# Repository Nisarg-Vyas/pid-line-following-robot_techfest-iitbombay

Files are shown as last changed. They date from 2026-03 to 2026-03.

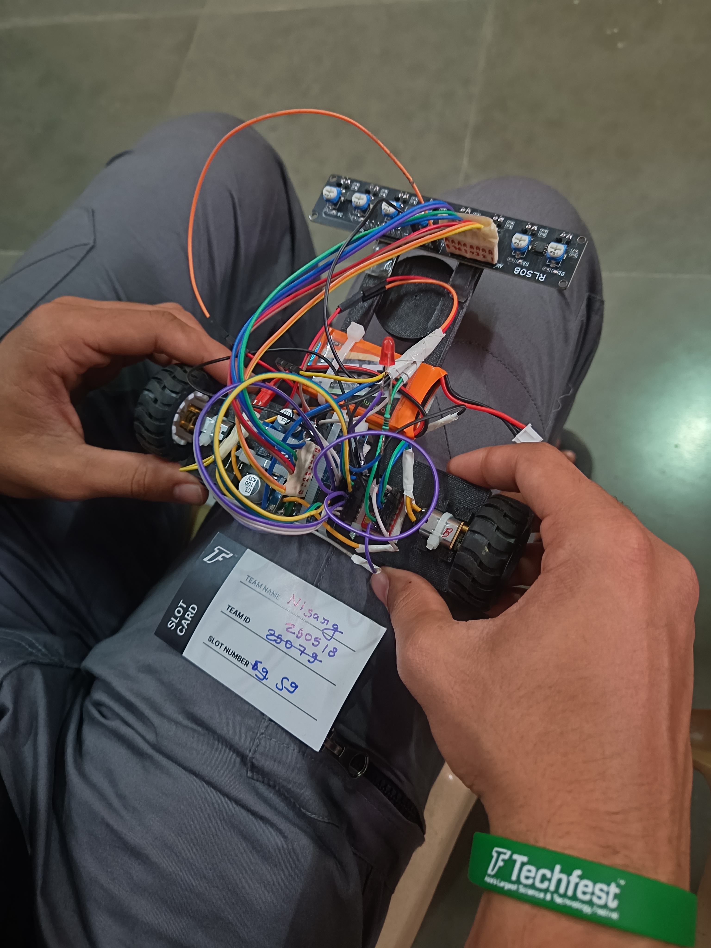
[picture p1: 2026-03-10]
images/lfr_1.jpg

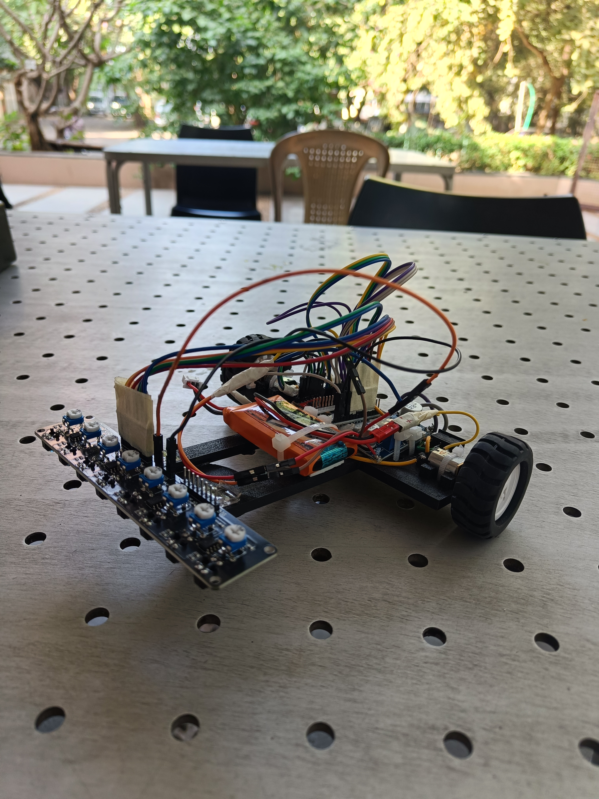
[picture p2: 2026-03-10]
images/lfr_2.jpg

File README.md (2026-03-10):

# PID Line Following Robot (Techfest IIT Bombay – Meshmerize)

A high-speed PID-based Line Following Robot designed for the **Meshmerize competition organised by Techfest IIT Bombay**.

The robot secured **3rd place in the Zonal round at IIT Gandhinagar** and directly qualified for the **final round**.

The robot uses an **8-channel reflectance sensor array**, a **PID control algorithm**, and a **dual H-bridge motor driver** to achieve stable and fast line tracking. (check [lfr_demo](videos/lfr_demo.mp4))

---

# Competition Performance

The robot performed very well in the zonal round and achieved **3rd position**, qualifying directly for the finals.

During the final round, the robot was tuned for **higher speed**, which caused the sensors to miss the line on sharp turns. However, at moderate speeds the robot was able to follow the track very accurately.

---

# Features

* PID based line following
* 8-channel reflectance sensor array
* Junction detection
* U-turn detection
* Dead-end detection
* Finish box detection
* Adjustable motor speed
* High-speed optimized control

---

# Hardware Components

Main components used:

* Arduino Nano
* QTR-8RC reflectance sensor array
* TB6612FNG motor driver
* N20 DC gear motors
* LiPo battery (7.4V)
* Buck converter for regulated voltage
* LEDs for status indication

The complete component list is available in:

[View COMPONENTS](docs/components.txt)

---

# System Architecture

The robot consists of three main subsystems:

### Sensor System

An **8-channel reflectance sensor array** reads the track.

Each sensor returns a value representing how much light is reflected from the surface.

* Dark line → low reflectance
* White surface → high reflectance

The sensors are read through the Arduino analog pins.

---

### Control System

The robot uses a **PID controller** to adjust motor speeds based on the line position.

The PID algorithm calculates the error between the detected line position and the center of the robot.

Correction formula:

```
correction = Kp * error + Kd * (error - lastError)
```

Motor speeds are adjusted accordingly to steer the robot back onto the line.

---

### Drive System

Two **N20 DC gear motors** drive the robot using a differential drive configuration.

The **TB6612FNG motor driver** controls direction and speed using PWM signals from the Arduino.

---

# Code Explanation

The control logic is implemented using a **state machine**.

States include:

* FOLLOW_LINE
* TURN_LEFT_STATE
* TURN_RIGHT_STATE
* UTURN_STATE
* FINISH_STATE

The robot continuously reads sensor values and determines which state to enter.

---

# Line Following Algorithm

The robot reads all 8 sensors and calculates a weighted average of their readings.

Example sensor weights:

```
{-3, -2, -1, -0.5, 0.5, 1, 2, 3}
```

These weights estimate the line position relative to the robot center.

The error is then fed into the PID controller to compute steering correction.

---

# Junction Detection

The robot checks specific sensors to determine junctions.

Left junction:

```
sensor[6] or sensor[7]
```

Right junction:

```
sensor[0] or sensor[1]
```

Straight path detection is based on center sensors.

---

# Dead-End Detection

If no valid path is detected, the robot identifies a **dead end** and performs a **U-turn**.

---

# Finish Detection

A white finish box is detected when all sensors detect a white surface for a sustained period.

Once detected:

* motors stop
* finish LED turns ON

---

# Pin Configuration

Motor Driver:

| Arduino Pin | Function |
| --- | --- |
| 7 | AIN1 |
| 6 | AIN2 |
| 5 | PWMA |
| 9 | BIN1 |
| 10 | BIN2 |
| 11 | PWMB |
| 8 | STBY |

Sensor Enable:

| Arduino Pin | Function |
| --- | --- |
| 4 | IR Sensor Enable |

Finish LED:

| Arduino Pin | Function |
| --- | --- |
| 13 | Finish Indicator |

Complete wiring details are available in:

docs/pinout_wiring.txt

---

# Future Improvements

* adaptive PID tuning
* higher sensor sampling rate
* dynamic speed control
* improved corner detection
* hardware encoder feedback

---

# Author
Nisarg Vyas  
B.Tech Computer Science and Engineering  
IIIT Vadodara (IIITV-ICD)

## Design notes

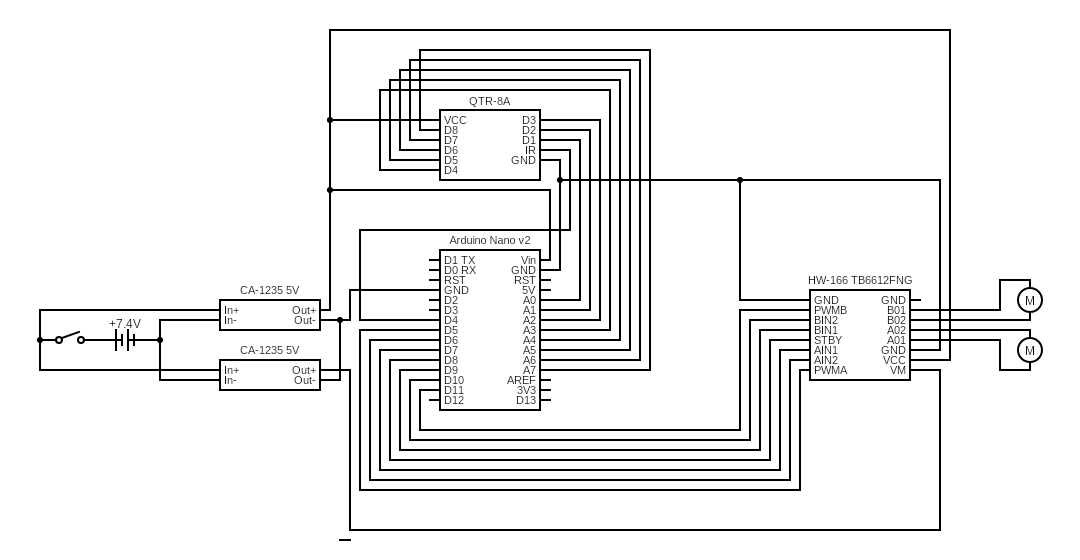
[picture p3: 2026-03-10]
docs/circuit.png

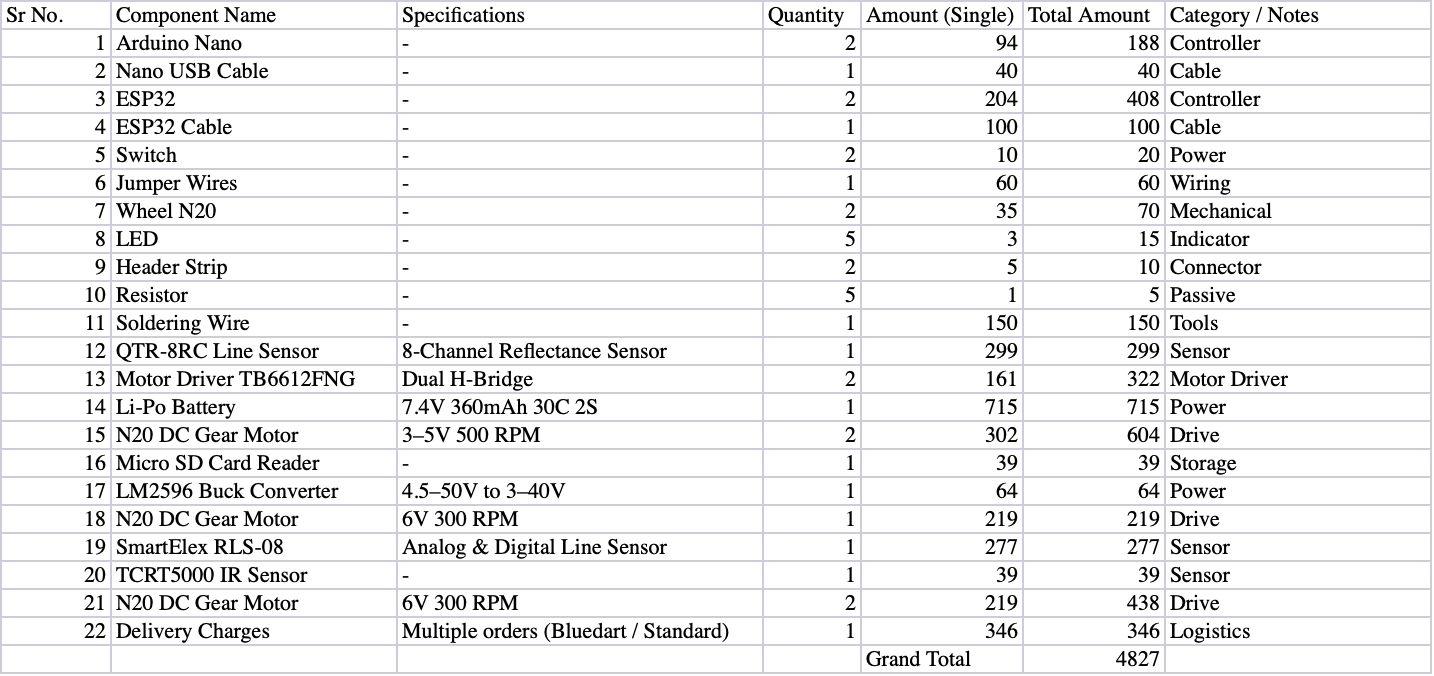
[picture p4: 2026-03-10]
docs/bill.png

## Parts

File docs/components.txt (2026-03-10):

LINE FOLLOWING ROBOT – COMPONENT LIST

1. Arduino Nano
   Microcontroller used for robot control

2. QTR-8RC Line Sensor
   8-channel reflectance sensor array for line detection

3. TB6612FNG Motor Driver
   Dual H-Bridge motor driver for controlling two DC motors

4. N20 DC Gear Motors
   6V / 300 RPM motors used for robot mobility

5. Wheels (N20 compatible)
   Mounted on motors for drive

6. Li-Po Battery
   7.4V 360mAh 30C (2S)

7. LM2596 Buck Converter
   Steps battery voltage down to regulated level

8. Switch
   Used for power control

9. Jumper Wires
   Electrical connections between modules

10. LEDs
   Status indicator and finish signal

11. Resistors
   Current limiting for LEDs

12. Header Pins
   Used for connections between modules

Total Estimated Cost ≈ ₹4827

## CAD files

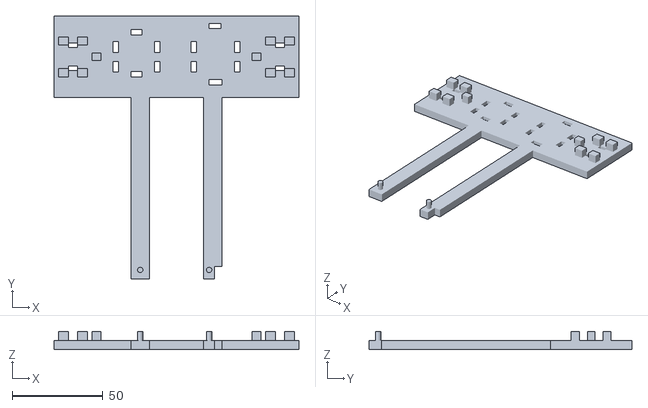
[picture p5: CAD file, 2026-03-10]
docs/lfr-chasis.stl
135.0 x 145.0 x 10.0

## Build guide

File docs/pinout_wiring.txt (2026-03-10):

LINE FOLLOWING ROBOT – PIN CONNECTIONS

Arduino Nano → Motor Driver (TB6612FNG)

D7  → AIN1
D6  → AIN2
D5  → PWMA

D9  → BIN1
D10 → BIN2
D11 → PWMB

D8  → STBY (Motor driver enable)

--------------------------------

Arduino Nano → Sensor Array

A0 → Sensor 1
A1 → Sensor 2
A2 → Sensor 3
A3 → Sensor 4
A4 → Sensor 5
A5 → Sensor 6
A6 → Sensor 7
A7 → Sensor 8

D4 → IR Sensor Enable

--------------------------------

Arduino Nano → Finish LED

D13 → LED Anode
GND → LED Cathode (through resistor)

--------------------------------

Power Connections

Battery → Buck Converter
Buck Converter 1 → Arduino 5V + Motor Driver Vcc
Buck Converter 2 → QTR (IR sensor)
Battery → Motor Driver VM
<*> NOTE: Power connecterion are different in "docs/pinout_wiring.txt"

All grounds connected together.

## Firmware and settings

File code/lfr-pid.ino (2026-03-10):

// ================= MOTOR DRIVER =================
#define AIN1 7
#define AIN2 6
#define PWMA 5
#define BIN1 9
#define BIN2 10
#define PWMB 11
#define STBY 8

// ================= SENSOR =================
#define IR_ENABLE 4

#define LINE_THRESHOLD   500
#define WHITE_THRESHOLD  800

// ================= FINISH LED =================
#define FINISH_LED 13

// ================= CALIBRATION =================
int minVal[8] = {324, 318, 293, 291, 287, 244, 357, 325};
int maxVal[8] = {956, 953, 939, 934, 929, 943, 952, 956};
int sensor[8];

float weight[8] = {-3, -2, -1, -0.5, 0.5, 1, 2, 3};

// ================= PID =================
float Kp = 25;
float Kd = 12;
int baseSpeed = 120;
float lastError = 0;

// ================= STATES =================
enum State {
  FOLLOW_LINE,
  TURN_LEFT_STATE,
  TURN_RIGHT_STATE,
  UTURN_STATE,
  FINISH_STATE
};

State robotState = FOLLOW_LINE;

// ================= FLAGS & TIMERS =================
bool turnLocked = false;
unsigned long deadEndTimer = 0;
unsigned long uTurnStartTime = 0;
unsigned long finishTimer = 0;

// =================================================
void setup() {

  pinMode(IR_ENABLE, OUTPUT);
  digitalWrite(IR_ENABLE, HIGH);

  pinMode(FINISH_LED, OUTPUT);
  digitalWrite(FINISH_LED, LOW);

  pinMode(AIN1, OUTPUT); pinMode(AIN2, OUTPUT);
  pinMode(BIN1, OUTPUT); pinMode(BIN2, OUTPUT);
  pinMode(PWMA, OUTPUT); pinMode(PWMB, OUTPUT);
  pinMode(STBY, OUTPUT);
  digitalWrite(STBY, HIGH);
}

// =================================================
void loop() {

  readSensors();

  // ===== WHITE FINISH CHECK (TOP PRIORITY) =====
  if (robotState == FOLLOW_LINE) {
    if (isWhiteFinishBox()) {
      robotState = FINISH_STATE;
    }
  }

  bool leftA, straightA, rightA;
  detectJunctions(leftA, straightA, rightA);

  bool whiteCandidate = allSensorsWhite();

  switch (robotState) {

    // ================= FOLLOW LINE =================
    case FOLLOW_LINE:

      // ---------- DEAD END (BLOCKED IF WHITE) ----------
      if (!whiteCandidate && !leftA && !straightA && !rightA) {

        if (deadEndTimer == 0)
          deadEndTimer = millis();

        if (millis() - deadEndTimer > 120) {
          robotState = UTURN_STATE;
          turnLocked = true;
          lastError = 0;
          uTurnStartTime = 0;
          deadEndTimer = 0;
        }
        break;
      }
      else {
        deadEndTimer = 0;
      }

      // ---------- PRIORITY ----------
      if (!turnLocked && leftA) {
        slowDown();
        turnLocked = true;
        robotState = TURN_LEFT_STATE;
        lastError = 0;
      }
      else if (!turnLocked && straightA) {
        followLinePID();
      }
      else if (!turnLocked && rightA) {
        slowDown();
        turnLocked = true;
        robotState = TURN_RIGHT_STATE;
        lastError = 0;
      }
      break;

    // ================= TURN LEFT =================
    case TURN_LEFT_STATE:
      turnLeft();
      readSensors();
      if (lineFound()) {
        robotState = FOLLOW_LINE;
        turnLocked = false;
        lastError = 0;
      }
      break;

    // ================= TURN RIGHT =================
    case TURN_RIGHT_STATE:
      turnRight();
      readSensors();
      if (lineFound()) {
        robotState = FOLLOW_LINE;
        turnLocked = false;
        lastError = 0;
      }
      break;

    // ================= U TURN =================
    case UTURN_STATE:

      if (uTurnStartTime == 0)
        uTurnStartTime = millis();

      uTurn();
      readSensors();

      if ((millis() - uTurnStartTime > 200) && lineFound()) {
        robotState = FOLLOW_LINE;
        turnLocked = false;
        lastError = 0;
        uTurnStartTime = 0;
      }

      if (millis() - uTurnStartTime > 700) {
        robotState = FOLLOW_LINE;
        turnLocked = false;
        uTurnStartTime = 0;
      }
      break;

    // ================= FINISH =================
    case FINISH_STATE:
      stopMotors();
      digitalWrite(FINISH_LED, HIGH);
      while (1);
  }
}

// ============ WHITE FINISH LOGIC =================

bool isWhiteFinishBox() {

  if (!allSensorsWhite()) {
    finishTimer = 0;
    return false;
  }

  if (finishTimer == 0)
    finishTimer = millis();

  if (millis() - finishTimer > 600)
    return true;

  return false;
}

bool allSensorsWhite() {
  for (int i = 0; i < 8; i++) {
    if (sensor[i] < WHITE_THRESHOLD)
      return false;
  }
  return true;
}

// ================= PID FOLLOW ====================

void followLinePID() {

  float sum = 0, total = 0;

  for (int i = 0; i < 8; i++) {
    int raw = analogRead(A0 + i);
    int val = map(raw, minVal[i], maxVal[i], 0, 1000);
    val = constrain(val, 0, 1000);

    sum += val * weight[i];
    total += val;
  }

  float error = (total != 0) ? sum / total : lastError;

  float correction = Kp * error + Kd * (error - lastError);
  lastError = error;

  int leftSpeed  = baseSpeed - correction;
  int rightSpeed = baseSpeed + correction;

  leftSpeed  = constrain(leftSpeed,  0, 255);
  rightSpeed = constrain(rightSpeed, 0, 255);

  digitalWrite(AIN1, LOW);
  digitalWrite(AIN2, HIGH);
  digitalWrite(BIN1, HIGH);
  digitalWrite(BIN2, LOW);

  analogWrite(PWMA, leftSpeed);
  analogWrite(PWMB, rightSpeed);
}

// ================= MOTION ========================

int turnSpeed() {
  if (baseSpeed <= 100) return 120;
  if (baseSpeed <= 120) return 160;
  return 180;
}

void slowDown() {
  analogWrite(PWMA, 70);
  analogWrite(PWMB, 70);
  delay(15);
}

void stopMotors() {
  analogWrite(PWMA, 0);
  analogWrite(PWMB, 0);
  digitalWrite(AIN1, LOW);
  digitalWrite(AIN2, LOW);
  digitalWrite(BIN1, LOW);
  digitalWrite(BIN2, LOW);
}

void turnLeft() {
  digitalWrite(AIN1, LOW);
  digitalWrite(AIN2, HIGH);
  digitalWrite(BIN1, LOW);
  digitalWrite(BIN2, HIGH);
  analogWrite(PWMA, turnSpeed());
  analogWrite(PWMB, turnSpeed());
}

void turnRight() {
  digitalWrite(AIN1, HIGH);
  digitalWrite(AIN2, LOW);
  digitalWrite(BIN1, HIGH);
  digitalWrite(BIN2, LOW);
  analogWrite(PWMA, turnSpeed());
  analogWrite(PWMB, turnSpeed());
}

void uTurn() {
  digitalWrite(AIN1, HIGH);
  digitalWrite(AIN2, LOW);
  digitalWrite(BIN1, HIGH);
  digitalWrite(BIN2, LOW);
  analogWrite(PWMA, turnSpeed());
  analogWrite(PWMB, turnSpeed());
}

// ================= SENSOR ========================

void readSensors() {
  for (int i = 0; i < 8; i++) {
    int raw = analogRead(A0 + i);
    sensor[i] = map(raw, minVal[i], maxVal[i], 0, 1000);
    sensor[i] = constrain(sensor[i], 0, 1000);
  }
}

// ============ JUNCTION DETECTION =================

void detectJunctions(bool &leftA, bool &straightA, bool &rightA) {

  leftA  = (sensor[6] < LINE_THRESHOLD || sensor[7] < LINE_THRESHOLD);
  rightA = (sensor[0] < LINE_THRESHOLD || sensor[1] < LINE_THRESHOLD);

  int centerCount = 0;
  for (int i = 2; i <= 5; i++) {
    if (sensor[i] < LINE_THRESHOLD)
      centerCount++;
  }
  straightA = (centerCount >= 2);
}

// ============ LINE CONFIRMATION ==================

bool lineFound() {
  int count = 0;
  for (int i = 2; i <= 5; i++) {
    if (sensor[i] < LINE_THRESHOLD)
      count++;
  }
  return (count >= 2);
}
